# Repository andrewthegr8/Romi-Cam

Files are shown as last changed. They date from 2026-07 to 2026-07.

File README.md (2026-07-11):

# Romi Pose Tracking System

This repository contains the deployment code and support files for a Romi pose tracking system. It is written for future students who need to run, maintain, or extend the project.

The system uses a Raspberry Pi camera setup to detect ArUco markers, sends pose packets from the Raspberry Pi to an ESP32 transmitter over SPI, broadcasts those packets over ESP-NOW, receives them on an ESP32 mounted on the Romi, and serves requested pose data to the STM32 over UART.

```text
Raspberry Pi + Camera
        |
        | SPI
        v
ESP32 Transmitter
        |
        | ESP-NOW broadcast
        v
ESP32 Receiver on Romi
        |
        | UART request/response
        v
STM32 on Romi
```

For background and validation details, see the thesis document associated with this project. This README focuses only on code deployment, repository contents, and physical device connections. Earlier Raspberry Pi development code is available in the related development repository: [RomiCam](https://github.com/andrewthegr8/RomiCam).

---

## Repository Layout

```text
ROMI-CAM/
├── ESP Receiver/
│   └── main.c
├── ESP Transmitter/
│   └── main.c
├── Raspberry Pi/
│   ├── D.json
│   ├── K.json
│   ├── RomiTrackerV9_helper.py
│   └── RomiTrackerV9.py
├── STM Code/
│   └── ESP_Comm.py
├── Support Files/
│   ├── CAD/
│   │   ├── NewCameraMount.SLDASM
│   │   ├── NewCameraMount.STL
│   │   ├── romi-ARUCO-mount.SLDASM
│   │   ├── romi-chassis-kit.step
│   │   ├── RomiMountv1.3MF
│   │   ├── threads.SLDPRT
│   │   └── threads.STL
│   ├── RealMarkerBoard.ai
│   └── RealMarkerBoard.pdf
└── README.md
```

### File and Folder Purposes

| Path | Purpose |
| --- | --- |
| `ESP Receiver/main.c` | ESP32 firmware for the board mounted on Romi. It receives ESP-NOW pose packets and responds to STM32 UART pose requests.  |
| `ESP Transmitter/main.c` | ESP32 firmware for the board connected to the Raspberry Pi. It acts as an SPI peripheral and broadcasts received pose packets over ESP-NOW. |
| `Raspberry Pi/RomiTrackerV9.py` | Main Raspberry Pi runtime script. It initializes the camera, runs the tracking callback, prints pose data to the terminal, and sends pose packets over SPI. |
| `Raspberry Pi/RomiTrackerV9_helper.py` | Helper code for calibration-file loading, ArUco detection setup, marker-to-world coordinate conversion, heading calculation, terminal display formatting, and packet construction. |
| `Raspberry Pi/K.json` | Camera intrinsic matrix used by the Raspberry Pi tracker. Keep this file in the Raspberry Pi working directory. |
| `Raspberry Pi/D.json` | Camera distortion coefficients used by the Raspberry Pi tracker. Keep this file in the Raspberry Pi working directory. |
| `STM Code/ESP_Comm.py` | MicroPython helper class used on the STM32 to request pose data from the ESP32 receiver over UART. |
| `Support Files/CAD/` | Mechanical support files for the Romi marker mount and Raspberry Pi/camera mounting hardware. |
| `Support Files/RealMarkerBoard.ai` | Adobe Illustrator version of the final calibration/marker pattern. |
| `Support Files/RealMarkerBoard.pdf` | PDF version of the final calibration/marker pattern. |

---

## Hardware Used by the Deployment

This deployment uses the following device roles:

| Device | Role |
| --- | --- |
| Raspberry Pi with camera | Captures frames, detects markers, builds pose packets, and sends packets over SPI. |
| ESP32-WROOM-32 development board, transmitter | Receives SPI data from the Raspberry Pi and broadcasts the packet using ESP-NOW. |
| ESP32-WROOM-32 development board, receiver | Receives ESP-NOW packets on the Romi and serves the latest pose data to the STM32 over UART. |
| STM32 on Romi | Requests pose data for a given Romi marker ID over UART. |
| Final marker board / calibration pattern | Fixed ArUco marker pattern used by the Raspberry Pi code to locate the world frame. |

### Power and Logic Levels

| Device | Power Source Used in This Deployment |
| --- | --- |
| Raspberry Pi | USB-C power supply. |
| ESP32 transmitter | USB cable from the Raspberry Pi. |
| ESP32 receiver on Romi | 5 V output from the STM32 board. |
| STM32 / Romi | Romi/STM32 power system. |

All SPI and UART logic connections are 3.3 V logic. Tie grounds together for every wired interface. Do not connect 5 V logic directly to SPI or UART signal pins.

---

## Raspberry Pi Software Setup

The Raspberry Pi code was developed on:

| Component | Known Working Version / Source |
| --- | --- |
| OS | Debian GNU/Linux 12 Bookworm |
| Python | 3.11.2 |
| `cv2` | 4.9.0 |
| `numpy` | 1.24.2 |
| `picamera2` | 0.0.31 |
| `spidev` | 3.8 |
| `gpiozero` | 2.0.1 |

The script was developed with older versions of some libraries. If you don't use versions close to these, be prepared to retest the camera and SPI pipeline.

### Install Python Dependencies

APT packages are preferred when available, especially for libraries that interface with Raspberry Pi hardware.

From the repository root on the Raspberry Pi:

```bash
sudo apt update
sudo apt install python3 python3-venv python3-pip python3-numpy python3-opencv python3-picamera2 python3-gpiozero python3-spidev
```

Create a virtual environment that can still see system-installed Raspberry Pi packages:

```bash
python3 -m venv --system-site-packages .venv
source .venv/bin/activate
```

If `spidev` is not available from APT on the target image, install it inside the virtual environment:

```bash
python -m pip install "spidev==3.8"
```

### Enable Raspberry Pi Interfaces

The tracker opens SPI device `/dev/spidev0.0`, which corresponds to SPI0 with CE0. Enable SPI on the Raspberry Pi before running the tracker.

The code uses `picamera2`, so the attached camera must be visible to the Raspberry Pi camera/libcamera stack.

### Required Runtime Files and Folders

Run the tracker from inside the `Raspberry Pi/` folder because `K.json`, `D.json`, and `debug_pics/` are referenced with relative paths.

```bash
cd "Raspberry Pi"
mkdir -p debug_pics
```

Keep these files in the same folder as `RomiTrackerV9.py`:

```text
Raspberry Pi/
├── D.json
├── K.json
├── RomiTrackerV9_helper.py
└── RomiTrackerV9.py
```

The `debug_pics/` folder is required because the helper writes initialization images into it.

---

## Raspberry Pi Tracker Runtime

Start the tracker from the `Raspberry Pi/` folder:

```bash
source ../.venv/bin/activate
python RomiTrackerV9.py
```

At startup, the script:

1. Starts the camera using `picamera2`.
2. Captures an initialization frame.
3. Loads `K.json` and `D.json`.
4. Writes initialization images into `debug_pics/`.
5. Detects the fixed locating markers.
6. Starts the camera callback loop.
7. Starts the SPI and terminal-printer threads.

During normal operation, the terminal displays a table with marker ID, position, heading, and frame timing data. Pose packets are sent to the ESP32 transmitter only after marker data is available.

Current Raspberry Pi runtime settings in `RomiTrackerV9.py`:

| Setting | Current Value |
| --- | --- |
| Camera main stream | `2304 x 1296`, `YUV420` |
| Camera sensor output | `2304 x 1296`, 10-bit |
| SPI device | `/dev/spidev0.0` |
| SPI mode | Mode 1, `0b01` |
| SPI clock | `6_000_000` Hz |
| Pose packet size | 163 bytes |
| SPI transfer size | 256 bytes, with the valid packet padded using zero bytes |
| Profiling GPIO in Python | GPIO 21 through `gpiozero.LED(21)` |

Stop the tracker with `Ctrl+C`. The current implementation doesn't have all threads exit gracefully, so you'll have to hit `Ctrl+C` a few times and wait for all the threads to hit an exception.

---

## Marker Board and Romi Marker Deployment

The Raspberry Pi code uses OpenCV's 4x4 ArUco dictionary with 50 available marker IDs:

```python
aruco.DICT_4X4_50
```

The fixed locating markers are hard-coded as marker IDs `0` through `10` in `RomiTrackerV9_helper.py`. The tracker ignores these IDs after initialization because they define the fixed reference pattern.

Use marker IDs `11` through `49` for Romis. The `ROMIID` used by the STM32 should match the ArUco marker ID mounted on the Romi.

Current deployment constants encoded in `RomiTrackerV9_helper.py`:

| Item | Current Value |
| --- | --- |
| Fixed locating marker IDs | `0, 1, 2, 3, 4, 5, 6, 7, 8, 9, 10` |
| Fixed locating marker width | `100.0` mm |
| Fixed locating marker coordinates | Stored in `MarkerCenters_mm` |
| Romi marker plane height used by the tracker | `130` mm |
| Current pose packet capacity | 10 Romi detections per packet |

Use the files in `Support Files/` for the physical setup:

| File / Folder | Use |
| --- | --- |
| `Support Files/RealMarkerBoard.ai` | Editable Adobe Illustrator version of the final marker board. |
| `Support Files/RealMarkerBoard.pdf` | Printable PDF version of the final marker board. (36 inches by 72 inches) - PRINT AT FULL SCALE! |
| `Support Files/CAD/romi-ARUCO-mount.SLDASM` | Romi ArUco marker mount assembly. |
| `Support Files/CAD/RomiMountv1.3MF` | 3MF version of the Romi marker mount. |
| `Support Files/CAD/NewCameraMount.SLDASM` / `.STL` | Camera/Raspberry Pi mounting hardware for the wooden stand. |
| `Support Files/CAD/romi-chassis-kit.step` | Romi chassis reference geometry. |
| `Support Files/CAD/threads.SLDPRT` / `.STL` | 3-D printable fasteners to constrain the mount of the wooden stand. |

If the marker board is printed at a different scale, the fixed marker dimensions or positions change, or the Romi marker height changes, update the corresponding constants in `RomiTrackerV9_helper.py` before running the system.

---

## ESP32 Firmware Setup

The ESP32 code was developed using ESP-IDF version 5.5 in VS Code with the Espressif extension.

Use two separate ESP32 boards:

| Board Label | Firmware Folder | Physical Location |
| --- | --- | --- |
| ESP32 Transmitter | `ESP Transmitter/main.c` | Near the Raspberry Pi. |
| ESP32 Receiver | `ESP Receiver/main.c` | Mounted on the Romi. |

The repository stores the application `main.c` files. If your local ESP-IDF workspace expects a full ESP-IDF project structure, create or open an ESP-IDF project in VS Code and place the corresponding `main.c` in that project's main application component.

Use ESP-IDF target `esp32` for ESP32-WROOM-32 development boards. Build and flash each board with the VS Code ESP-IDF workflow.

### ESP-NOW Broadcast Behavior

Both ESP32 programs use ESP-NOW on Wi-Fi channel 1. The transmitter sends to the broadcast MAC address:

```c
FF:FF:FF:FF:FF:FF
```

That is intentional. Any ESP32 receiver running the matching receiver firmware and listening on the same Wi-Fi channel can receive the pose packets. This allows multiple Romis to receive the same broadcast stream without pairing each transmitter/receiver pair by MAC address.

---

## Raspberry Pi to ESP32 Transmitter Wiring

The Raspberry Pi is the SPI controller. The ESP32 transmitter is the SPI peripheral.

| Raspberry Pi Pin | Raspberry Pi Function | ESP32 Transmitter Pin | ESP32 Function |
| --- | --- | --- | --- |
| BCM GPIO 10 | SPI0 MOSI | GPIO 23 | `GPIO_MOSI` |
| BCM GPIO 9 | SPI0 MISO | GPIO 19 | `GPIO_MISO` |
| BCM GPIO 11 | SPI0 SCLK | GPIO 18 | `GPIO_SCLK` |
| BCM GPIO 8 | SPI0 CE0 / CS | GPIO 5 | `GPIO_CS` |
| GND | Ground | GND | Ground reference |

The transmitter firmware also defines a handshake pin on ESP32 GPIO 2. The current Raspberry Pi Python script does not read a handshake GPIO, so the handshake pin is not used in this deployment.

---

## ESP32 Receiver to STM32 Wiring

The ESP32 receiver uses `UART_NUM_2` on the ESP32 side and communicates with the STM32 over UART at 115200 baud. The STM32 MicroPython setup uses `UART(3)`.

| ESP32 Receiver Pin | STM32 / MicroPython Pin | Direction | Notes |
| --- | --- | --- | --- |
| GPIO 17 | `Pin.cpu.C11` / UART3 RX | ESP32 TX to STM32 RX | ESP32 sends the 12-byte pose response. |
| GPIO 16 | `Pin.cpu.C10` / UART3 TX | STM32 TX to ESP32 RX | STM32 sends the 4-byte pose request. |
| GND | GND | Shared reference | Required. |

Power the ESP32 receiver from the STM32 board's 5 V output as used in the deployed system, but keep the UART signal lines at 3.3 V logic.

If you wish to use these exact pins for UART on the STM32, follow this MicroPython setup pattern. The `Pin.cpu.C4` and `Pin.cpu.C5` lines are included because these are the default pins for UART3 and have to be remapped after the `UART` object is instantiated if alternate pins are being used.

```python
from pyb import Pin, UART
from ESP_Comm import ESP_Comm

# ROMIID must match the ArUco marker ID mounted on the Romi.
ROMIID = 11

# Init UART object for communication with ESP32.
Pin(Pin.cpu.C10, Pin.ALT, alt=7)  # UART3 TX
Pin(Pin.cpu.C11, Pin.ALT, alt=7)  # UART3 RX
uart_esp = UART(3, 115200)

# Set pin modes back to default for UART3 remapping.
Pin(Pin.cpu.C4, mode=Pin.ANALOG)
Pin(Pin.cpu.C5, mode=Pin.ANALOG)

esp_comm = ESP_Comm(uart_esp, ROMIID)
```

---

## STM32 Pose Request Code

Copy `STM Code/ESP_Comm.py` onto the STM32 MicroPython filesystem so it can be imported by the Romi control code.

Minimal usage:

```python
pose = esp_comm.get_pose()

if pose is not None:
    x_in, y_in, heading_deg = pose
```

The included `ESP_Comm.py` helper performs this transaction:

1. Send a 4-byte UART request to the ESP32 receiver.
2. Wait 2 ms for the ESP32 receiver to process the request.
3. Read a 12-byte UART response.
4. Unpack the response as three little-endian floats.

The request bytes are:

| Byte | Value | Meaning |
| --- | --- | --- |
| 0 | `ROMIID` | Requested Romi marker ID. |
| 1 | `0x0A` | Newline terminator byte. |
| 2 | `0x0A` | Newline terminator byte. |
| 3 | `0x0A` | Newline terminator byte. |

The ESP32 receiver response is 12 bytes:

| Bytes | Type | Meaning |
| --- | --- | --- |
| 0-3 | `float32`, little-endian | `center_x` in millimeters on the wire. |
| 4-7 | `float32`, little-endian | `center_y` in millimeters on the wire. |
| 8-11 | `float32`, little-endian | Heading in degrees. |

Important unit note: the wire protocol uses millimeters for `center_x` and `center_y`, but the included `ESP_Comm.py` helper divides `x` and `y` by `25.4` before returning them. Therefore `ESP_Comm.get_pose()` currently returns `x` and `y` in inches, and heading in degrees. To work in millimeters on the STM32, remove the `/25.4` conversion in `ESP_Comm.py` or multiply the returned `x` and `y` values by `25.4`.

---

## Pose Packet Layout

The Raspberry Pi builds a fixed 163-byte pose packet before padding the SPI transfer to 256 bytes.

All multi-byte numeric values are little-endian.

| Byte Offset | Size | Type | Field | Notes |
| --- | ---: | --- | --- | --- |
| `0` | 1 byte | `uint8` | Header byte 0 | Always `0x5A`. |
| `1` | 1 byte | `uint8` | Header byte 1 | Always `0x5A`. |
| `2` | 1 byte | `uint8` | Packet depth | Number of detected Romi markers included in this packet. |
| `3 + 16*i` | 4 bytes | `float32` | Marker ID | Stored as a float in the current packet format. |
| `7 + 16*i` | 4 bytes | `float32` | Center x | Millimeters. |
| `11 + 16*i` | 4 bytes | `float32` | Center y | Millimeters. |
| `15 + 16*i` | 4 bytes | `float32` | Heading | Degrees. |

`i` is the packet entry index, currently `0` through `9` for up to 10 Romi detections per packet.

The ESP32 receiver stores the most recent pose by marker ID. When the STM32 requests `ROMIID`, the receiver returns the latest stored `(center_x, center_y, heading)` for that ID.

---

## Code Configuration Values Most Likely to Change

Future contributors should keep these values synchronized across the repository when extending the project.

| Change | Files to Inspect |
| --- | --- |
| Change the SPI pins | `ESP Transmitter/main.c`, Raspberry Pi wiring, and any Pi-side SPI setup changes. |
| Change the UART pins | `ESP Receiver/main.c`, STM32 MicroPython UART setup, and wiring. |
| Change the number of Romis per packet | `Raspberry Pi/RomiTrackerV9.py`, `Raspberry Pi/RomiTrackerV9_helper.py`, `ESP Transmitter/main.c`, `ESP Receiver/main.c`, and any STM32 parsing assumptions. |
| Change marker board geometry | `Support Files/RealMarkerBoard.*` and `MarkerCenters_mm` / `MarkerWidth_mm` in `Raspberry Pi/RomiTrackerV9_helper.py`. |
| Change camera, lens, or calibration | `Raspberry Pi/K.json`, `Raspberry Pi/D.json`, and the camera configuration in `Raspberry Pi/RomiTrackerV9.py`. |
| Change Romi marker height | The `Zw` value passed to `pixel_to_world(...)` in `Raspberry Pi/RomiTrackerV9_helper.py`. |
| Change ESP-NOW channel | `WIFI_CHANNEL` in both ESP32 source files. |
| Change the STM request format | `STM Code/ESP_Comm.py` and the UART request parsing in `ESP Receiver/main.c`. |

When changing the packet layout, update all layers together: Raspberry Pi packet builder, ESP32 transmitter packet length, ESP32 receiver unpacking, and STM32 response parsing.

---

## Normal Deployment Sequence

1. Mount the Raspberry Pi and camera on the wooden stand using the support hardware.
2. Place or attach the final marker board where the camera can see locating markers `0` through `10`.
3. Mount an ArUco marker on the Romi using the Romi marker mount.
4. Set `ROMIID` in the STM32 code to the ArUco marker ID mounted on that Romi.
5. Wire the Raspberry Pi to the ESP32 transmitter over SPI.
6. Wire the ESP32 receiver to the STM32 over UART.
7. Power the Raspberry Pi, ESP32 transmitter, Romi/STM32, and ESP32 receiver.
8. Flash the transmitter firmware to the ESP32 connected to the Raspberry Pi.
9. Flash the receiver firmware to the ESP32 mounted on the Romi.
10. Copy `STM Code/ESP_Comm.py` to the STM32 MicroPython filesystem and import it from the Romi control code.
11. Start the Raspberry Pi tracker from the `Raspberry Pi/` folder.
12. In the Romi code, call `esp_comm.get_pose()` whenever the STM32 needs the latest pose estimate.

---

## Notes for Future Development

The current code is organized around a working deployment, not a general-purpose library. The values in the Python helper, ESP32 firmware, and STM32 helper are tightly coupled to the deployed wiring, marker IDs, packet format, and calibration files. Deviations from the exact setup described here will likely require (potentially extensive) code changes to get the system working again.

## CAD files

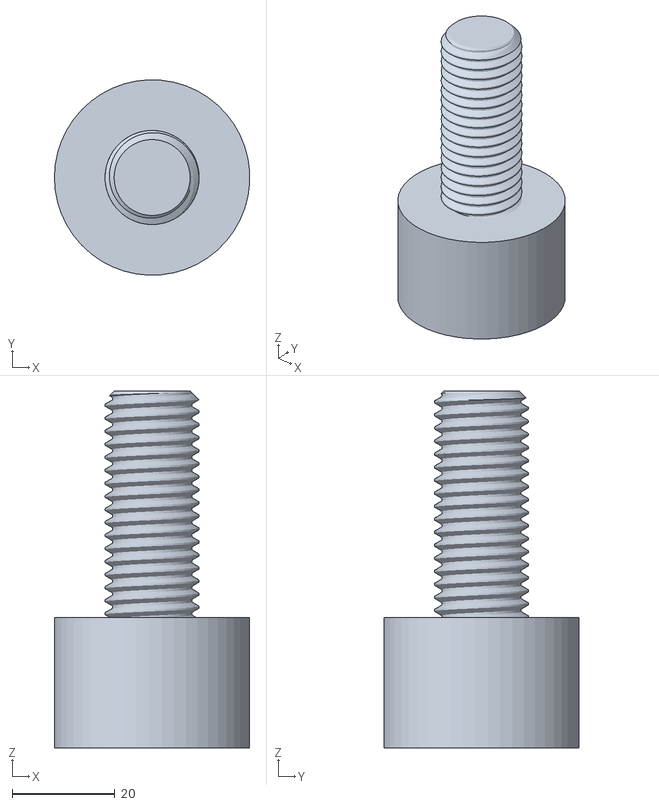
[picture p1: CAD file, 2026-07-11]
Support Files/CAD/threads.STL
38.1 x 38.1 x 69.6

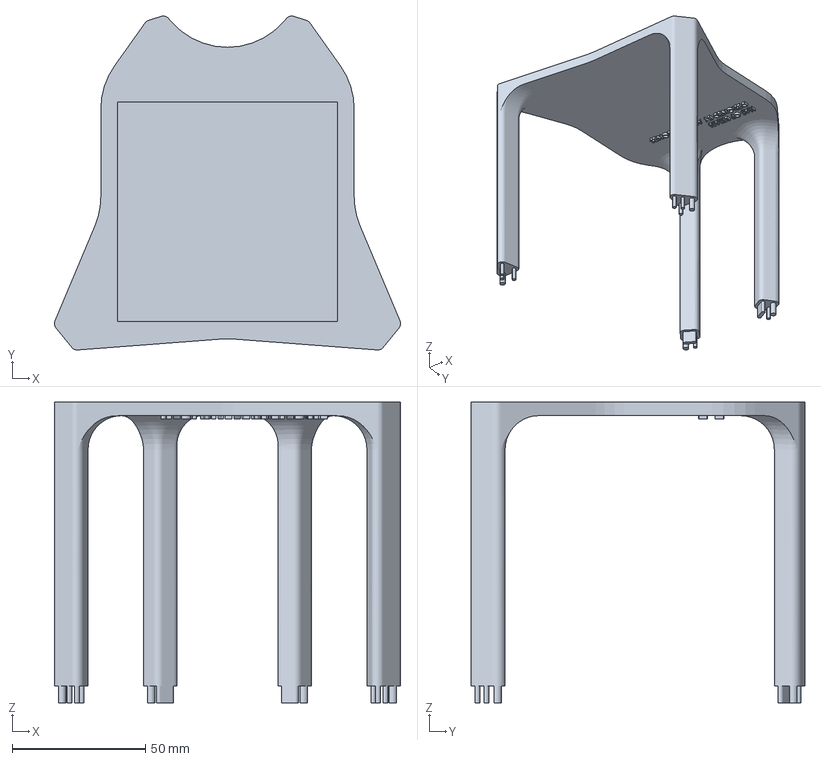
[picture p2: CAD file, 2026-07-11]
Support Files/CAD/RomiMountv1.3MF
130.1 x 125.5 x 113.0 mm

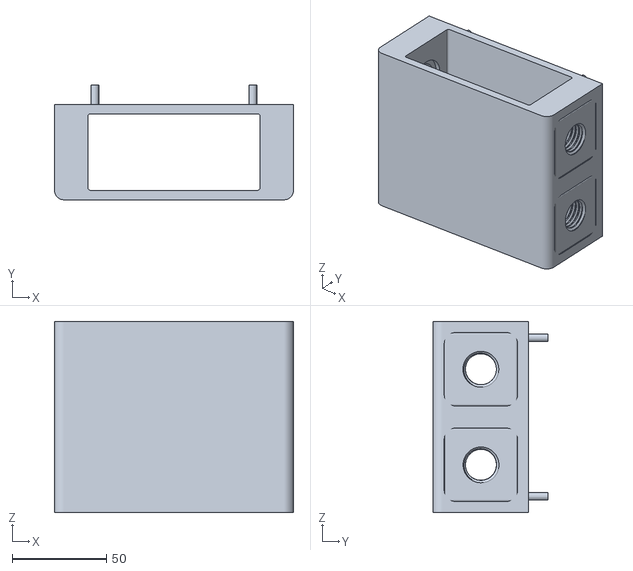
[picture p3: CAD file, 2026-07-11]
Support Files/CAD/NewCameraMount.STL
127.0 x 61.0 x 101.6

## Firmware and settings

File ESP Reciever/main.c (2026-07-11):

#include <stdio.h>
#include <stdlib.h>
#include <time.h>
#include <string.h>
#include <assert.h>
#include "freertos/FreeRTOS.h"
#include "freertos/semphr.h"
#include "freertos/timers.h"
#include "nvs_flash.h"
#include "esp_event.h"
#include "esp_netif.h"
#include "esp_wifi.h"
#include "esp_log.h"
#include "esp_mac.h"
#include "esp_now.h"
#include "esp_crc.h"
#include "driver/spi_slave.h"
#include "driver/gpio.h"
#include "driver/uart.h"

#define ESPNOW_MAXDELAY 512

#define LOGGING 0 //Toggle to compile with/without detailed logging

//Some setup stuff
#define WIFI_CHANNEL 1 //Set the wifi channel ESPNOW operates on
#define WIFI_MODE WIFI_MODE_STA //ESPNOW can work in both station and softap mode - arbitrarily selecting station mode
#define WIFI_IF WIFI_IF_STA //Interface ESPNOW peer operates on. MUST MATCH WIFI_MODE

//Define UART end transaction pattern
#define UART_END_PATTERN 0x0A//This is the pattern char we send over UART to signal the end of a packet transmission to the STM. The STM should listen for this pattern to know when a full packet has been received and can be processed

//More setup stuff
uint8_t broadcast_mac[ESP_NOW_ETH_ALEN] = { 0xFF, 0xFF, 0xFF, 0xFF, 0xFF, 0xFF }; //This is the mac we're broadcasting to (Everyone)
static const char* TAG = "Reciever"; //Tag for logging

//GPIO Pin configuration
#define RCV_HOST    SPI2_HOST
#define GPIO_UART_TX      17
#define GPIO_UART_RX      16

//Define Inter-task communication flags
#define UART_TRANS_NOT_IN_PROG   (1U << 0)
#define DATA_UPDATE_NOT_IN_PROG  (1U << 0)



typedef struct {
    uint8_t mac_addr[ESP_NOW_ETH_ALEN];
    uint8_t *data;
    int data_len;
} espnow_event_cb_data_t; //This is the format of the data that is passed to the espnow callback function


//PACKET CONFIG
#define NUMROMIS 50 //Max ID number that can occur/ max number of Romis we can have in a packet
//^WE NEED THIS TO BE 50 TO DETECT UP TO ID NUMBER 49, not because we expect to get pose data for 50 Romis
//Pose data type - for easily storing pose data in memory
typedef struct {
            struct{ //Data for each Romi - 12 bytes each (center x, center y, heading)
                float center_x;
                float center_y;
                float heading;
    } romi_data[NUMROMIS]; //Assuming max 10 Romis per packet
} pose_data_t;
#define PACKETSIZE NUMROMIS*16 + 3 //packet size (pose data plus header and num of romis detected)


typedef struct { //Data that will get passed to Watchdog task
    pose_data_t *pose_data; //Pointer to pose data heap var
    EventGroupHandle_t event_group; //Event group handle
} packet_watchdog_task_params_t;

typedef struct { //Data that will get passed to UART task
    pose_data_t *pose_data; //Pointer to pose data heap var
    EventGroupHandle_t event_group; //Event group handle
} uart_task_params_t;


//print packer data helper function
//void print_data(packet_t * packet_struct) {
//    if (packet_struct->header[0] != 0x5A || packet_struct->header[1] != 0x5A) {
//        printf("Invalid packet header! Got %02X %02X\n", packet_struct->header[0], packet_struct->header[1]);
//        return;
//    }
//    printf("Received packet with %d Romi poses:\n", packet_struct->numRomi);
//    for (int i = 0; i < packet_struct->numRomi; i++) {
//    printf("Romi ID: %f, Center Position (%f, %f), Heading %f\n",
//                packet_struct->romi_data[i].id,
//                packet_struct->romi_data[i].center_x,
//                packet_struct->romi_data[i].center_y,
//                packet_struct->romi_data[i].heading
//            );
//    }
//}


//SKETCHY!!
//Initialize queue handle as global variable so we can access it in callbacks
//Stupid esp_now_register_recieve_cb doesn't allow passing args to callback
//I thought this was a bad idea but this is what the ESP example code does
QueueHandle_t packet_queue_handle = NULL;
QueueHandle_t uart_event_queue_handle = NULL;



/* WiFi should start before using ESPNOW */
//Initialize wifi using example wifi init function
void wifi_init(void) { //Basic Wifi setup
    ESP_ERROR_CHECK(esp_netif_init());                            //Initialize underlying TCP/IP stack
    ESP_ERROR_CHECK(esp_event_loop_create_default());             //Create default event loop
    esp_netif_create_default_wifi_sta();                          //Apparently this is needed for initializing wifi in station mode
    wifi_init_config_t cfg = WIFI_INIT_CONFIG_DEFAULT();          //Set wifi config to default
    ESP_ERROR_CHECK( esp_wifi_init(&cfg) );                       //Allocate resources for WiFi driver and start WiFi task
    ESP_ERROR_CHECK( esp_wifi_set_storage(WIFI_STORAGE_RAM) );    //Set the WiFi API configuration storage type (Set to RAM)
    ESP_ERROR_CHECK( esp_wifi_set_mode(WIFI_MODE) );          //Set wifi mode
    ESP_ERROR_CHECK( esp_wifi_start());                           //Start wifi with current configuration
    ESP_ERROR_CHECK( esp_wifi_set_channel(WIFI_CHANNEL, WIFI_SECOND_CHAN_NONE));
    #if LOGGING
    ESP_LOGI(TAG, "WiFi initialized");
    #endif
}

//Define ESPnow call back function
//This function throws the packet into a queue. It needs to be lightweight
void espnow_recv_cb(const esp_now_recv_info_t *recv_info, const uint8_t *data, int len){
    #if LOGGING
    ESP_LOGI(TAG, "Got packet in callback!");
    ESP_LOGI(TAG, "Data length: %d", len);
    ESP_LOGI(TAG, "Data in callback: %02X %02X %02X %02X %02x %02x %02x %02x %02x %02x %02x", data[0], data[1], data[2], data[3], data[4], data[5], data[6], data[7], data[8], data[9], data[10]); //Print first 11 bytes of packet for debugging
    #endif
    xQueueOverwrite(packet_queue_handle, ( void * const ) data); //Push packet data into the queue. Will overwrite so we only keep most recent value
}

//initialize ESPnow
void espnow_init(void)
{
    /* Initialize ESPNOW and register sending and receiving callback function. */
    ESP_ERROR_CHECK( esp_now_init() );
    //This is where we would init send/recieve callbacks
    ESP_ERROR_CHECK( esp_now_register_recv_cb(espnow_recv_cb) ); //Register callback function to handle packets
    /* Add broadcast peer information to peer list. */
    esp_now_peer_info_t peer = {0};     //Create peer information structure and fill with zeros
    //Fill relevant structure fields
    peer.channel = WIFI_CHANNEL;
    peer.ifidx = WIFI_IF;
    peer.encrypt = false; //Disable encryption (not necessary)
    memcpy(peer.peer_addr, broadcast_mac, ESP_NOW_ETH_ALEN); //Copy mac address from broadcast mac structure to appropriate field
    ESP_ERROR_CHECK( esp_now_add_peer(&peer) ); // add peer to the peer list (pass pointer to peer struct)
    #if LOGGING
    ESP_LOGI(TAG, "ESPNOW initialized");
    #endif
}

//UART Setup
void UART_init(void) {
    //Configure UART parameters
    const uart_config_t uart_config = {
        .baud_rate = 115200,
        .data_bits = UART_DATA_8_BITS,
        .parity = UART_PARITY_DISABLE,
        .stop_bits = UART_STOP_BITS_1,
        .flow_ctrl = UART_HW_FLOWCTRL_DISABLE,
        .source_clk = UART_SCLK_DEFAULT,
    };
    //define these as variables for readibility (they'll disappear when this function exits)
    int rx_buff_size = 256;
    int tx_buff_size = 256;
    int freertos_queue_size = 5;
    int interrupt_flag = 0; //Default - allows driver to set interrupt flags

    esp_err_t driver_install = uart_driver_install(UART_NUM_2, rx_buff_size, tx_buff_size, freertos_queue_size, &uart_event_queue_handle, interrupt_flag);
    assert(driver_install == ESP_OK);
    esp_err_t param_set = uart_param_config(UART_NUM_2, &uart_config);
    assert(param_set == ESP_OK);
    esp_err_t pin_set = uart_set_pin(UART_NUM_2, GPIO_UART_TX, GPIO_UART_RX, -1, -1);
    assert(pin_set == ESP_OK);

    //Setup UART driver to trigger event when end of message is detected.
    uint8_t num_of_end_chars = 3; //Require 3 terminator bytes so one frame only triggers one pattern event
    esp_err_t pattern_enable = uart_enable_pattern_det_baud_intr(UART_NUM_2, UART_END_PATTERN, num_of_end_chars, 9, 0, 0);
    assert(pattern_enable == ESP_OK);
    esp_err_t pattern_queue_reset = uart_pattern_queue_reset(UART_NUM_2, 8);
    assert(pattern_queue_reset == ESP_OK);

    assert(uart_event_queue_handle != NULL);


    //Enable pull-ups on UART lines so we don't detect rogue pulses when nothing is connected.
    gpio_set_pull_mode(GPIO_UART_TX, GPIO_PULLUP_ONLY);
    gpio_set_pull_mode(GPIO_UART_RX, GPIO_PULLUP_ONLY);

    #if LOGGING
    ESP_LOGI(TAG, "UART interface initialized");
    #endif
}

void UART_event_task(void * params)
{
    //Pull stuff from parameters structure
    uart_task_params_t *uart_task_params = (uart_task_params_t *)params; //cast void pointer to appropriate struct pointer
    pose_data_t* pose_data_buff = uart_task_params->pose_data;
    EventGroupHandle_t event_group = uart_task_params->event_group;

    uart_event_t event; //allocate variable to get uart event from queue
    size_t buffer_len; //allocate var to get amount of uart received data buffered
    int bytes_read = 0;
    unsigned char request[4] = {0};
    uint8_t requested_id = 0;
    unsigned char tx_buff[12] = {0}; //Buffer to hold response data (pose data for 1 Romi)

    while (1) {
        if (xQueueReceive(uart_event_queue_handle, &event, portMAX_DELAY) == pdTRUE) { //Wait until something is successfully received from queue
            //DESIGN DECISION: FORCE NICE BEHAVIOR FROM STM.
            //IF MORE THAN 4 BYTES IN BUFFER, CLEAR
            //IF BUFFER FULL, CLEAR
            #if LOGGING
            ESP_LOGI(TAG, "UART event!");
            #endif
            //Only handle pattern detected or fifo overflow.
            if (event.type == UART_PATTERN_DET) { //If custom end of transmission detected
                //Make sure there's not too much in the buffer
                uart_get_buffered_data_len(UART_NUM_2, &buffer_len);
                if (buffer_len != 4) {
                    #if LOGGING
                    ESP_LOGI(TAG, "Got RX buffer length of %d, ignoring", buffer_len);
                    #endif
                    uart_flush_input(UART_NUM_2); //clear buffer
                    continue;
                };
                //Read from UART RX buffer and see if anything useful is there
                bytes_read = uart_read_bytes(UART_NUM_2, request, sizeof(request), pdMS_TO_TICKS(20)); //Read 4 bytes
                if (bytes_read != sizeof(request)) {
                    #if LOGGING
                    ESP_LOGI(TAG, "UART read returned %d bytes (expected %d), flushing RX", bytes_read, sizeof(request));
                    #endif
                    uart_flush_input(UART_NUM_2);
                    continue;
                }
                memcpy(&requested_id, request, sizeof(uint8_t)); //First byte of request is the ID of the Romi the STM is requesting data for. Copy to variable
                //Sanity check
                if (requested_id >= NUMROMIS) {
                    #if LOGGING
                    ESP_LOGI(TAG, "Got request for Romi ID [%d], which is out of bounds. Ignoring.", requested_id);
                    #endif
                    continue;
                };
                #if LOGGING
                ESP_LOGI(TAG, "Got request for Romi ID [%d]", requested_id);
                #endif
                //Now we know the ID of the Romi the STM is requesting data for. We just need to copy the appropriate data into the request buffer and send it back over UART
                xEventGroupWaitBits(event_group, DATA_UPDATE_NOT_IN_PROG, pdFALSE, pdFALSE, portMAX_DELAY); //Wait until watchdog isn't updating data (data is safe to read)
                //Clear flag to indicate UART transaction in progress so watchdog won't update data
                xEventGroupClearBits(event_group, UART_TRANS_NOT_IN_PROG);
                memcpy(tx_buff, &pose_data_buff->romi_data[requested_id], sizeof(pose_data_buff->romi_data[requested_id]));
                #if LOGGING
                ESP_LOGI(TAG, "tx buffer dump: %02X %02X %02X %02X %02X %02X %02X %02X %02X %02X %02X %02X",
                         tx_buff[0], tx_buff[1], tx_buff[2], tx_buff[3], tx_buff[4], tx_buff[5], tx_buff[6], tx_buff[7], tx_buff[8], tx_buff[9], tx_buff[10], tx_buff[11]);
                #endif

                xEventGroupSetBits(event_group, UART_TRANS_NOT_IN_PROG); //Set flag to indicate UART transaction not in progress so watchdog can update data again
                uart_write_bytes(UART_NUM_2, (const char *)tx_buff, sizeof(tx_buff)); //Write response payload
                //term_written = uart_write_bytes(UART_NUM_2, (const char *)&tx_terminator, 1); //Frame terminator for STM parser
            } else if (event.type == UART_FIFO_OVF) { //If RX buffer overflow detected or buffer full
                #if LOGGING
                ESP_LOGI(TAG, "RX fifo overflow");
                #endif
                uart_flush_input(UART_NUM_2); //Clear buffer
            };
        };
    }
}
void packet_watchdog_task(void * params)
{
    //Pull stuff from parameters structure
    packet_watchdog_task_params_t *packet_watchdog_task_params = (packet_watchdog_task_params_t *)params; //cast void pointer to appropriate struct pointer
    pose_data_t* pose_data_buff = packet_watchdog_task_params->pose_data;
    EventGroupHandle_t event_group = packet_watchdog_task_params->event_group;

    //Allocate buffer on the stack to pull packet into from queue
    unsigned char packet_buff[PACKETSIZE];
    memset(packet_buff, 0, sizeof(packet_buff)); //init to zeros
    uint8_t packet_depth = 0; //Useful depth of packet (3rd byte of packet)
    float current_id_f = 0.0; //current Romi ID
    uint8_t current_id = 0; //current Romi ID
    #if LOGGING
    ESP_LOGI(TAG, "Packet Watchdog task started");
    //Init vars for watchdog update profiling
    uint64_t start = 0;
    uint64_t count = 0;
    uint64_t runsum = 0;
    uint64_t end = 0;
    start = esp_timer_get_time();
    #endif
    while (1) { //Do this forever
        //Pull from queue. Will block until there's something in queue (or timeout is hit)
        if( xQueueReceive(packet_queue_handle, &packet_buff, portMAX_DELAY) == pdTRUE) { //Wait until something is successfully received from queue
            /*packet_buff now contains a copy of the packet. */
            #if LOGGING
            ESP_LOGI(TAG, "Packet Watchdog task got packet!");
            start = esp_timer_get_time();
            count++;
            #endif

            /*Packet validation goes here*/
            if (!((packet_buff[0] == 0x5A) && (packet_buff[1] == 0x5A))) { //if packet header not detected
                #if LOGGING
                ESP_LOGI(TAG, "Invalid packet header! Got %02X %02X", packet_buff[0], packet_buff[1]);
                #endif
                continue;
            };

            #if LOGGING
            ESP_LOGI(TAG, "packet dump incoming!");
            for (size_t i = 0; i < sizeof(packet_buff); i++)
            {
                printf("%02x ", packet_buff[i]);
            };
            printf("\n");
            #endif


            //Block if UART transaction is in progress
            xEventGroupWaitBits(event_group, UART_TRANS_NOT_IN_PROG, pdFALSE, pdFALSE, portMAX_DELAY);
            //event group handle, bit to wait to be set, don't clear bit on function return, don't wait for multiple bits, max timeout

            //Set data write flag so uart task doesn't try to write while we're modifying data
            xEventGroupClearBits(event_group, DATA_UPDATE_NOT_IN_PROG);

            //Now read the packt into heap variable
            #if LOGGING
            printf("Packet received with header %02X %02X and depth %d\n", packet_buff[0], packet_buff[1], packet_buff[2]);
            #endif
            packet_depth = packet_buff[2];
            for (int i = 0; i < packet_depth; i++){
                memcpy(&current_id_f, &packet_buff[3+(16*i)], sizeof(float)); //copy id to current_id float variable
                current_id = (uint8_t)current_id_f; //convert to a unsigned integer
                #if LOGGING
                ESP_LOGI(TAG, "Romi ID in packet: %d", current_id);
                #endif
                //Sanity check
                if (current_id >= NUMROMIS) {
                    #if LOGGING
                    ESP_LOGI(TAG, "Got Romi ID [%d] which is out of bounds, skipping", current_id);
                    #endif
                    continue; //Skip this set of data
                };
                //Now, here's where the magic happens. We're gonna copy the data into the heap variable IN THE CORRECT ORDER
                //So, pose_data_buff[1] is the data for romi w/ ID = 1, etc.
                //This is why we can't have current_id > NUMROMIS
                memcpy(&pose_data_buff->romi_data[current_id].center_x, &packet_buff[3+(16*i)+4], sizeof(float));
                memcpy(&pose_data_buff->romi_data[current_id].center_y, &packet_buff[3+(16*i)+8], sizeof(float));
                memcpy(&pose_data_buff->romi_data[current_id].heading, &packet_buff[3+(16*i)+12], sizeof(float));
            };
            #if LOGGING
            ESP_LOGI(TAG, "ensure memcpy worked properly:");
            const uint8_t *pose_bytes = (const uint8_t *)pose_data_buff;
            for (size_t i = 0; i < sizeof(*pose_data_buff); i++)
            {
                printf("%02x ", pose_bytes[i]);
            };
            printf("\n");
            #endif
            //Now that pose_data_buff has the latest data, set flag and go back to waiting
            xEventGroupSetBits(event_group, DATA_UPDATE_NOT_IN_PROG);

            #if LOGGING
            end = esp_timer_get_time();
            runsum += end - start;
            if ((count % 10) == 0) {
                printf("Average watchdog hotloop time: %lld\n", runsum/count);
            }
            ESP_LOGI(TAG, "Packet copied to UART buffer");
            //print_data((packet_t *)packet_buff); //Unpack and print packet data for debugging
             #endif
        }
    }
}

//from chat to see info about tasks
void print_tasks(void)
{
    char buffer[1024];
    vTaskList(buffer);
    printf("Task Name\tState\tPrio\tStack\tNum\n");
    printf("%s\n", buffer);
}


void app_main(void)
{
    //Need to init NVS before wifi
    // Initialize NVS
    esp_err_t ret = nvs_flash_init();
    if (ret == ESP_ERR_NVS_NO_FREE_PAGES || ret == ESP_ERR_NVS_NEW_VERSION_FOUND) {
        ESP_ERROR_CHECK( nvs_flash_erase() );
        ret = nvs_flash_init();
    }
    ESP_ERROR_CHECK(ret);

    //Init Wifi, ESPnow, SPI
    wifi_init();
    espnow_init();
    #if LOGGING
    ESP_LOGI(TAG, "Initialization complete, starting tasks...");
    #endif

    //Init buffer for Pose data
    pose_data_t *pose_data_ptr =(pose_data_t *)malloc(sizeof(pose_data_t));
    memset(pose_data_ptr, 0, sizeof(*pose_data_ptr)); //init to zeros


    //Init queue for passing packet from ESP callback to Watchdog task
    QueueHandle_t packet_queue = xQueueCreate(1, PACKETSIZE);
    //Write to global queue handle so we can access it in the callback function
    packet_queue_handle = packet_queue;
    //Initialize UART driver/event queue (uart_event_queue_handle is assigned by driver install)
    UART_init();

    //Init Event group for inter-task communication
    EventGroupHandle_t event_group = xEventGroupCreate();
    //Set both flags
    xEventGroupSetBits(event_group, (UART_TRANS_NOT_IN_PROG | DATA_UPDATE_NOT_IN_PROG));

    #if LOGGING
    ESP_LOGI(TAG, "Queues and event group for inter-task communication created");
    #endif

    //Setup structure to pass parameters to the Packet Watchdog task
    packet_watchdog_task_params_t *packet_watchdog_task_params = malloc(sizeof(packet_watchdog_task_params_t));
    //Set pointer to SPI transaction send buffer in the parameters structure so the Packet Watchdog task can access it
    packet_watchdog_task_params->pose_data = pose_data_ptr; //Pointer to buffer of pose data
    packet_watchdog_task_params->event_group = event_group; //Handle to event group


    //Setup structure to pass parameters to the SPI reciever task
    uart_task_params_t *uart_task_params = malloc(sizeof(uart_task_params_t));
    uart_task_params->pose_data = pose_data_ptr; //Pointer to buffer of pose data
    uart_task_params->event_group = event_group;

    #if LOGGING
    ESP_LOGI(TAG, "Task parameter structures allocated and configured");
    #endif


    //Create a task to send ESPNOW messages and pass pointer to task parameters structure to it
    xTaskCreatePinnedToCore(packet_watchdog_task, "Packet Watchdog Task", 4096, packet_watchdog_task_params, 4, NULL, 1); //Pin to core 1 to keep it off the wifi core
    //Create a task to send ESPNOW messages and pass pointer to SPI transaction config to it
    xTaskCreatePinnedToCore(UART_event_task, "UART Event Task", 8192, uart_task_params, 4, NULL, 1); //Pin to core 1 to keep it off the wifi core
    #if LOGGING
    ESP_LOGI(TAG, "Tasks created, entering main loop...");
    #endif
    print_tasks(); //Peek behind the scenes

}

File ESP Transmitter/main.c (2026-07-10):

#include <stdio.h>
#include <stdlib.h>
#include <time.h>
#include <string.h>
#include <assert.h>
#include "freertos/FreeRTOS.h"
#include "freertos/semphr.h"
#include "freertos/timers.h"
#include "nvs_flash.h"
#include "esp_event.h"
#include "esp_netif.h"
#include "esp_wifi.h"
#include "esp_log.h"
#include "esp_mac.h"
#include "esp_now.h"
#include "esp_crc.h"
#include "driver/spi_slave.h"
#include "driver/gpio.h"

#define ESPNOW_MAXDELAY 512

#define LOGGING 0 //Toggle to compile with/without detailed logging

//Some setup stuff
#define WIFI_CHANNEL 1 //Set the wifi channel ESPNOW operates on
#define WIFI_MODE WIFI_MODE_STA //ESPNOW can work in both station and softap mode - arbitrarily selecting station mode
#define WIFI_IF WIFI_IF_STA //Interface ESPNOW peer operates on. MUST MATCH WIFI_MODE



//More setup stuff
uint8_t broadcast_mac[ESP_NOW_ETH_ALEN] = { 0xFF, 0xFF, 0xFF, 0xFF, 0xFF, 0xFF }; //This is the mac we're broadcasting to (Everyone)
static const char* TAG = "Transmitter"; //Tag for logging

//GPIO Pin configuration
#define RCV_HOST    SPI2_HOST

#define GPIO_HANDSHAKE      2
#define GPIO_MOSI           23
#define GPIO_MISO           19
#define GPIO_SCLK           18
#define GPIO_CS             5



typedef struct { //Data that will get passed to ESPnow task
    uint8_t dest_mac[6]; //Mac addresses where packet will be sent
    QueueHandle_t queue; //packet queue handle
} espnow_task_params_t;

typedef struct { //Data that will be passed to SPI task
    spi_slave_transaction_t *transaction_t_pointer; //Pointer to spi_slave_transaction data structure
    QueueHandle_t queueptr; //packet queue handle
} spi_task_params_t;

//PACKET DEFINITION
#define PACKET_STRUCT_IMPLEMENTED 0 //Remove this and #if once packet_struct_t is implemented
#if PACKET_STRUCT_IMPLEMENTED
//Packet structure - for unpacking the raw bytes we get from SPI into something more usable
typedef struct {
    uint8_t header[2]; //Header bytes (0x5A 0x5A)
    uint8_t numRomi; //Number of Romis in this packet
    struct { //Data for each Romi - 16 bytes each (ID, center x, center y, heading)
        float id;
        float center_x;
        float center_y;
        float heading;
    } romi_data[NUMROMIS]; //Assuming max 10 Romis per packet
} packet_t;

#define NUMROMIS 10
#define PACKET_SIZE sizeof(packet_t)

#else
#define PACKET_SIZE 168 //Packet size (in bytes)
#define ROMI_DATA_LEN 16 //Each Romi has 16 bytes of data (ID (float), center x, center y, heading)
//Packet type - for SPI -> ESP-NOW queue
typedef struct {           
     unsigned char data[PACKET_SIZE];          //Packet data (usigned bytes)
} packet_t;
#endif





/* WiFi should start before using ESPNOW */
//Initialize wifi using example wifi init function
void wifi_init(void) //Basic wifi setup
//passing everything to ESP_ERROR_CHECK function to make sure everything inits properly
{
    ESP_ERROR_CHECK(esp_netif_init());                            //Initialize underlying TCP/IP stack
    ESP_ERROR_CHECK(esp_event_loop_create_default());             //Create default event loop
    esp_netif_create_default_wifi_sta();                          //Apparently this is needed for initializing wifi in station mode
    wifi_init_config_t cfg = WIFI_INIT_CONFIG_DEFAULT();          //Set wifi config to default
    ESP_ERROR_CHECK( esp_wifi_init(&cfg) );                       //Allocate resources for WiFi driver and start WiFi task
    ESP_ERROR_CHECK( esp_wifi_set_storage(WIFI_STORAGE_RAM) );    //Set the WiFi API configuration storage type (Set to RAM)
    ESP_ERROR_CHECK( esp_wifi_set_mode(WIFI_MODE) );          //Set wifi mode
    ESP_ERROR_CHECK( esp_wifi_start());                           //Start wifi with current configuration
    ESP_ERROR_CHECK( esp_wifi_set_channel(WIFI_CHANNEL, WIFI_SECOND_CHAN_NONE));
    #if LOGGING
    ESP_LOGI(TAG, "WiFi initialized");
    #endif
}


//initialize ESPnow
void espnow_init(void)
{
    /* Initialize ESPNOW and register sending and receiving callback function. */
    ESP_ERROR_CHECK( esp_now_init() );
    //This is where we would init send/recieve callbacks
    
    /* Add broadcast peer information to peer list. */
    esp_now_peer_info_t peer = {0};     //Create peer information structure and fill with zeros
    //Fill relevant structure fields
    peer.channel = WIFI_CHANNEL;
    peer.ifidx = WIFI_IF;
    peer.encrypt = false; //Disable encryption (not necessary)
    memcpy(peer.peer_addr, broadcast_mac, ESP_NOW_ETH_ALEN); //Copy mac address from broadcast mac structure to appropriate field
    ESP_ERROR_CHECK( esp_now_add_peer(&peer) ); // add peer to the peer list (pass pointer to peer struct)
    #if LOGGING
    ESP_LOGI(TAG, "ESPNOW initialized");
    #endif
}

//Task which send stuff over ESPNow
void espnow_send_task(void *params)
{
    //Pull stuff from parameters structure
    espnow_task_params_t *espnow_task_params = (espnow_task_params_t *)params; //cast void pointer to appropriate struct pointer
    QueueHandle_t packet_queue_handle = espnow_task_params->queue;

    //Allocate buffer on the stack to pull packet into from queue
    unsigned char packet_buff[PACKET_SIZE];
    #if LOGGING
    ESP_LOGI(TAG, "ESPNow send task started");
    #endif
    while (1) { //Do this forever
        //Pull from queue. Will block until there's something in queue (or timeout is hit)
        if( xQueueReceive(packet_queue_handle, &packet_buff, portMAX_DELAY) == pdTRUE) { //Wait until something is successfully received from queue

            /*packet_buff now contains a copy of the packet. */
                /*Packet validation goes here*/
            
            #if LOGGING
            ESP_LOGI(TAG, "ESPNOW task got packet!");
            #endif
            //Now that we've gotten a packet, send it with espnow
            esp_err_t send_result = esp_now_send(espnow_task_params->dest_mac, packet_buff, PACKET_SIZE);
            if (send_result != ESP_OK) {
            #if LOGGING
            ESP_LOGE(TAG, "Error sending the packet over ESPNow: %s", esp_err_to_name(send_result));
            #endif
                //abort(); //Give up and die
                //This should be improved so sending fails gracefully
                //Setup event handling in espnow_send callback
            }
            #if LOGGING
            ESP_LOGI(TAG, "Packet sent over ESPNow!");
            #endif            
        }
    }
}
//SPI Setup and Tasks

//Callback Functions
//Called after a transaction is queued and ready for pickup by master. We use this to set the handshake line high.
void my_post_setup_cb(spi_slave_transaction_t *trans)
{
    gpio_set_level(GPIO_HANDSHAKE, 1);
}

//Called after transaction is sent/received. We use this to set the handshake line low.
void my_post_trans_cb(spi_slave_transaction_t *trans)
{
    gpio_set_level(GPIO_HANDSHAKE, 0);
}
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
